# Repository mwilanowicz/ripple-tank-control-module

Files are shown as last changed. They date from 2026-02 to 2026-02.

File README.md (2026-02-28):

# Ripple Tank Control Module
### Engineering Thesis Project | Defended: 9th July, 2024

<p align="center">
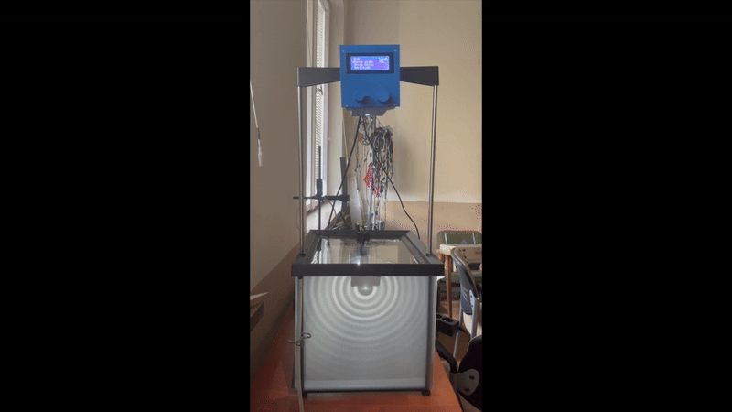
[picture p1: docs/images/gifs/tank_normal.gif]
  
</p>

## Project Overview
This project presents the design and construction of a specialized control module for a **ripple tank:** a laboratory instrument used to demonstrate wave phenomena. The module provides precise regulation of wave parameters and incorporates a stroboscopic effect to "freeze" water ripples for detailed observation.

### Project Scope & Engineering Cycle
The project covers the entire engineering cycle, demonstrating a multidisciplinary approach to hardware design:

* **Electronics:** Advanced circuit design featuring **dual-channel Op-Amp buffers (LM358)**, high-current **MOSFET power stages (IRL540)** for 9V peripherals, and custom DAC implementation via RC filtering.

* **Software:** Real-time, low-jitter signal generation using **AVR Timer1 interrupts (ISR)** for synchronized stroboscopic effects and signal modulation.

* **Mechanics:** Custom-designed housing and mounts developed in **SolidWorks**, optimized for structural stability and laboratory ergonomics.

---

## 1. Project Evolution: From CAD to Reality

A key part of this project was the integration of mechanical design with electronics. The enclosure was designed from scratch in SolidWorks to accommodate the custom internal hardware and user interface.

<div align="center">

| View | 3D CAD Model (SolidWorks) | Final Physical Prototype |
| :---: | :---: | :---: |
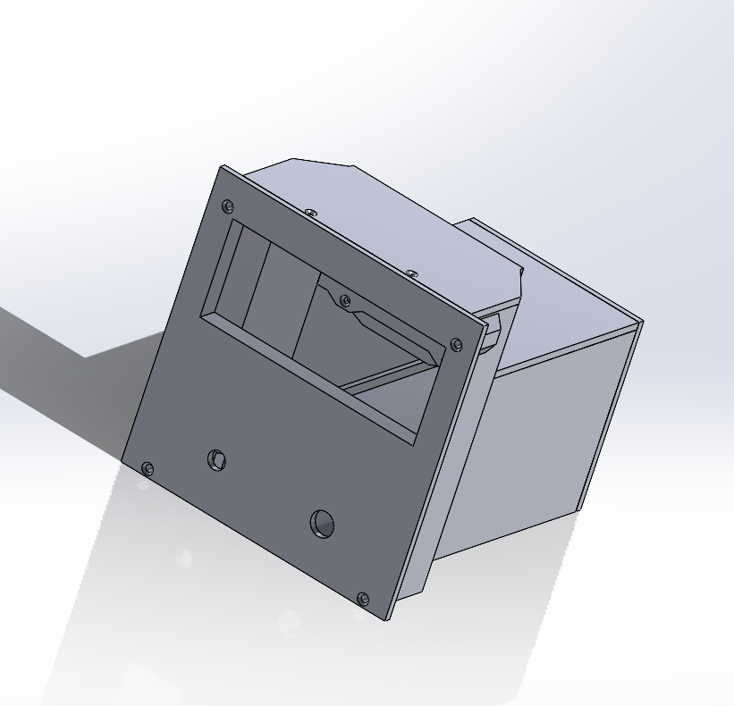
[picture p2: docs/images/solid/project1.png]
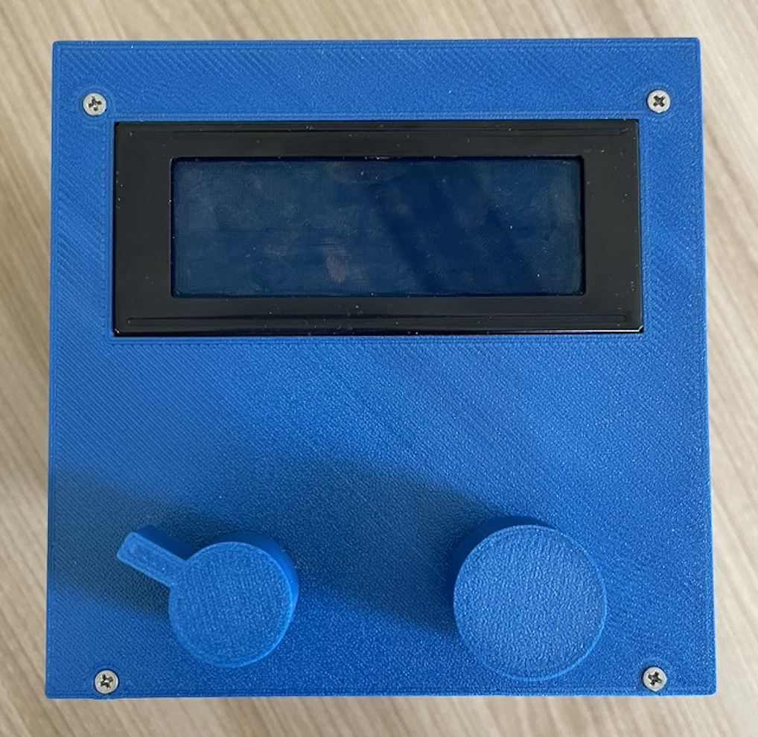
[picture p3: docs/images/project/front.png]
| **Front** |  |  |
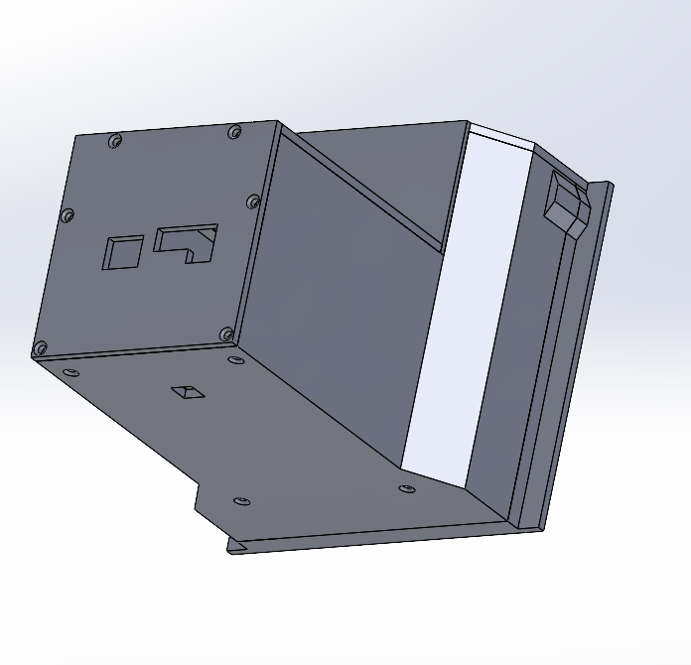
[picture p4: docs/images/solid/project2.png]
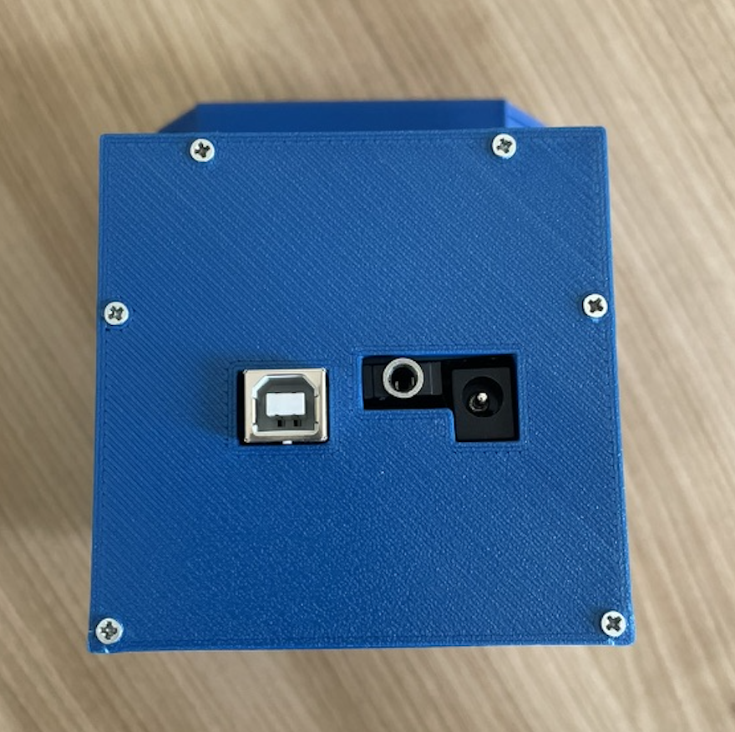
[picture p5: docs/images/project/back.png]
| **Back** |  |  |

</div>

### 1.1 Design Philosophy & Ergonomics
The housing was designed with a clear separation between control and connectivity:

* **Front Panel (User Interface):** Optimized for real-time experimentation. It features:
  * **LCD 20x4 display** for telemetry, 
  
  * **Rotary Encoder** for parameter tuning, 
  
  * **Analog Potentiometer** for high-precision frequency control.

* **Back Panel (Connectivity):** Houses the system's "engine" and external links. Features include:
    * **USB-B Port:** Direct access to the Arduino for firmware updates and serial monitoring.
    
    * **12V DC Power Socket:** Main power input (internally regulated/clamped to 9V by the system for optimal Arduino and peripheral stability).
    
    * **3.5mm Mini-Jack Output:** Dedicated high-current connection for the mechanical actuator (speaker membrane) of the ripple tank system.
    
### 1.3 Internal Layout & Thermal Management
The internal architecture was designed to handle the physical constraints of high-power components within a 3D-printed enclosure:

* **Mounting & Durability:** The top panel features an **integrated mounting point with a heat-set brass insert**. This allows for a robust, threaded connection to the apparatus, preventing the wear and tear typical of threading directly into plastic.

* **Thermal Mitigation Strategy:** High-power resistors and the stroboscopic LED are mounted on a **factory-grade metal plate**. While not a thermal insulator, the plate provides two critical advantages:
    * **Air Gap & Contact Prevention:** It ensures that the heat-generating components have no direct contact with the PLA housing, preventing localized melting.
    * **Passive Heat Spreading:** It acts as a primary heat spreader, distributing thermal energy across its surface area before it reaches the enclosure walls.

* **Internal Clearances:** All internal mounts were modeled in SolidWorks to ensure perfectly aligned access to the USB-B, 3.5mm Jack, and DC Power ports, while maintaining sufficient airflow around the Arduino Proto-Shield.

**Files for 3D printing (STL) can be found here:** [`./hardware/stl`](./hardware/stl)

---

## 2. System Description & Electronics

The hardware architecture is centered around the ATmega328P microcontroller, featuring dedicated analog stages for signal conditioning, power management, and user interface control.

### 2.1 Component Mapping & Signal Path

| Component | Physical Pin | Technical Implementation | Function |
| :--- | :--- | :--- | :--- |
| **Rotary Encoder** | **D5, D6 (Input)** | Digital (Internal Pull-up) | Menu navigation & parameter adjustment |
| **Push Button** | **D7 (Input)** | Digital (Internal Pull-up) | Toggle layers & settings (short) / Save to EEPROM (long) |
| **Potentiometer** | **A1 (Input)** | Analog + Software Hysteresis | Frequency Input: Stable 1–100 Hz adjustment |
| **Speaker** | **D9 (Output)** | Shunt (BC547B) + Buffer + IRL540 | **9V Wave Actuator:** High-speed frequency switching |
| **Strobe LED** | **D4 (Output)** | Buffer (LM358) + MOSFET (IRL540) | **9V Optical Sync:** Precision stroboscopic flash |
| **Arduino Signal** | **D11 (Output)** | PWM + RC Filter ($10\text{k}\Omega/100\mu\text{F}$) | **Amplitude Control:** High-fidelity analog voltage |
| **LCD (I2C 0x3F)** | **A4, A5 (I/O)** | I2C Communication (20x4) | Real-time UI & parameter feedback display |

### 2.2 Circuit Design & Hardware Implementation
The system architecture is based on a structured schematic designed to ensure signal integrity and efficient power distribution. The hardware was implemented as a high-fidelity prototype using a **point-to-point wiring** approach on an Arduino Proto-Shield.

<p align="center">
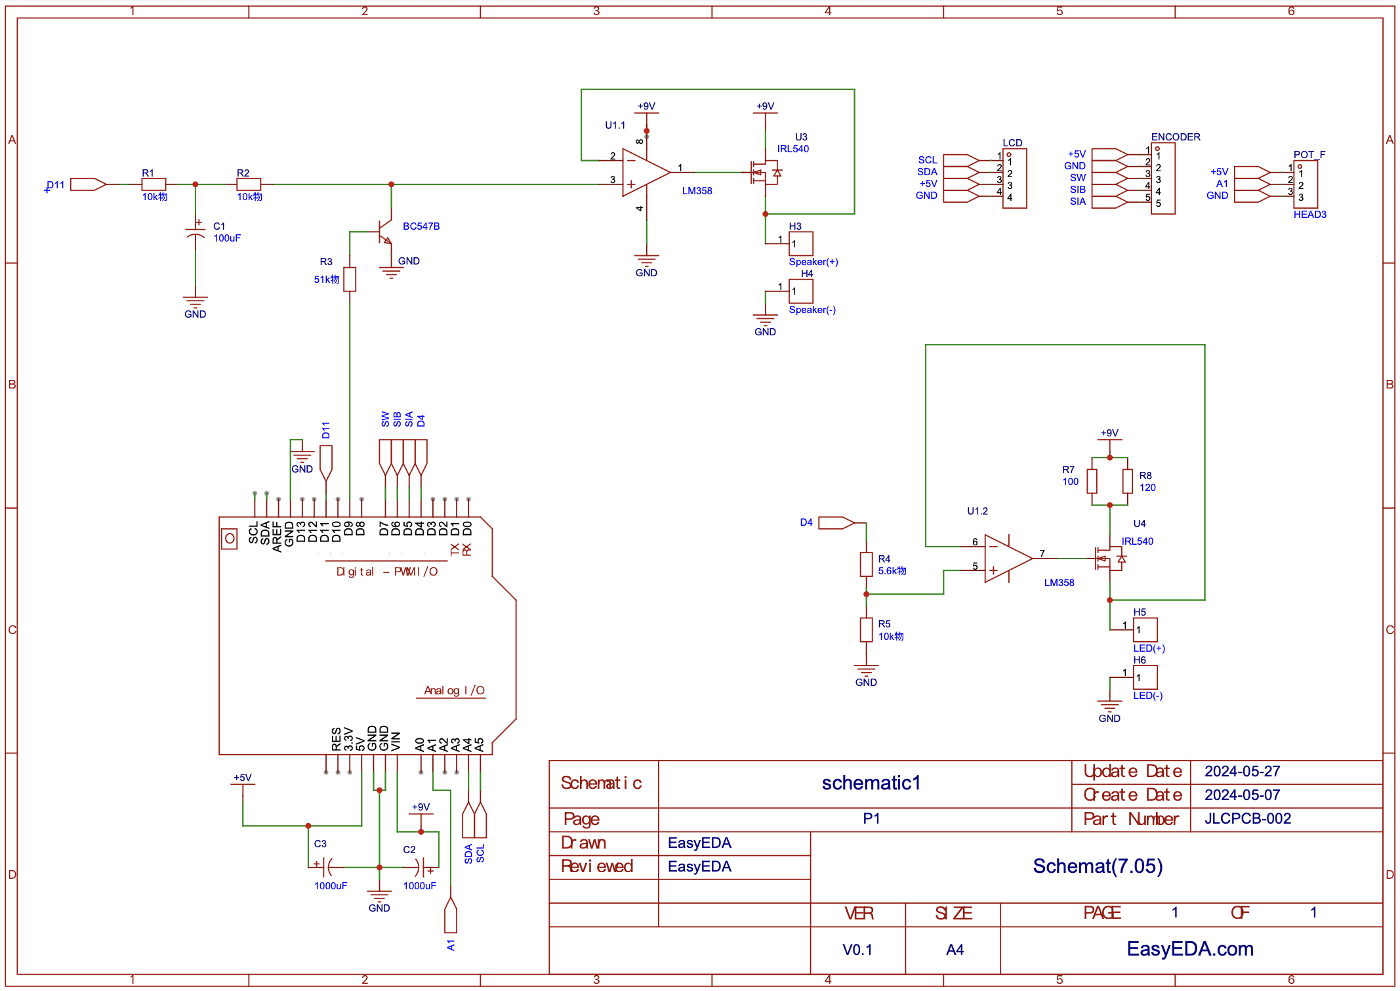
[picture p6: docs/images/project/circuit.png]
Full Electronics Schematic
  
  <br>
  <a href="docs/images/project/circuit_eda.pdf"><strong>📄 Download Full Schematic (PDF)</strong></a>
</p>

To manage high-current loads and overcome the lack of a built-in DAC, the circuit incorporates a dual-channel analog stage with high-current isolation:

* **Control Interface & Signal Modulation:**
    * **Analog Potentiometer (A1):** Dedicated to real-time **Frequency control (D9)**. Provides immediate response by mapping the analog value to `Timer1` registers.
        
      * **Frequency Modulation:** A **BC547B NPN shunt** on pin D9 "chops" the DC reference to ground, providing zero-latency frequency switching without affecting the RC-filter capacitor's charge.
       
    * **Rotary Encoder (D5, D6, D7):** Manages the digital UI menu and fine-tunes the following parameters:
    
      * **Amplitude (D11)**: Generated via a PWM-to-DC **RC filter** ($10\text{k}\Omega / 100\mu\text{F}$). Adjusts the **PWM duty cycle**, which the RC filter converts into an analog voltage reference.
  
      * **Strobe Width (D4)**: Sets the duration of the LED flash within the interrupt cycle to eliminate motion blur. 
  
      * **Pulse Delay (D4)**: Adjusts the phase shift between the mechanical wave and the light pulse, allowing the user to "freeze" the wave at different points in its cycle.

* **Dual Active Buffering (LM358):** 
  * Both the Wave Actuator and Stroboscopic LED channels utilize an **LM358 Op-Amp** configured as a **Voltage Follower**. This provides high input impedance to protect the control signals and low output impedance to drive the power MOSFETs without voltage drops.

* **High-Power Output Stage (9V Rail):** 
  * Two **IRL540 Power MOSFETs** act as the final drivers for the actuator and LED. By drawing current directly from the **9V power rail**, they isolate the 5V logic from high-current spikes and prevent system instability.

* **Stroboscopic LED Precision:** The LED drive includes a voltage divider ($5.6\text{k}\Omega / 10\text{k}\Omega$) and **parallel power resistors** to distribute heat dissipation, ensuring the high-intensity LED operates at a safe 3.2V / 100mA point.

* **Power Integrity:** Massive **1000µF decoupling capacitors** are placed across both the 5V and 9V rails to stabilize the supply during simultaneous operation of the mechanical actuator and LED pulses.
  
---

## 3. Software Architecture & Implementation

The firmware focuses on non-blocking execution and low-level hardware control.

### 3.1 Functional Specification

- **PWM and Pulse Control**
Frequency, duty cycle, and pulse parameters are generated using **Timer1 in CTC mode** for high precision. This allows for manual control over the AVR timers (`TCCR1A`, `TCCR1B`), essential for scientific experiments where timing jitter must be minimized.

- **Software Optimization (Lookup Table)**
To ensure instantaneous response and minimize CPU overhead, frequency calculations are performed using a pre-calculated **Lookup Table**. Each entry maps a target frequency to specific **OCR1A** register values.

  **Timer1 Calculation Example ($f_{clk} = 16 \text{ MHz}$):**

    * **100 Hz:** $\frac{16,000,000}{(624+1) \cdot 1} = 25600 \text{ Hz}$ (Internal Interrupt) $\rightarrow 100 \text{ Hz}$ (Final Output)

    * **1 Hz:** $\frac{16,000,000}{(62499+1) \cdot 1} = 256 \text{ Hz}$ (Internal Interrupt) $\rightarrow 1 \text{ Hz}$ (Final Output)
  
<details>
  <summary><b>Click to expand full Frequency Lookup Table (1 Hz – 100 Hz)</b></summary>

| Step (ISR Freq) | Target Frequency | Period ($T$) | OCR1A Value |
| :--- | :--- | :--- | :--- |
| 256 Hz | **1 Hz** | 1000.0 ms | 62499 |
| 512 Hz | **2 Hz** | 500.0 ms | 31249 |
| 768 Hz | **3 Hz** | 333.3 ms | 20832 |
| 1024 Hz | **4 Hz** | 250.0 ms | 15624 |
| 1280 Hz | **5 Hz** | 200.0 ms | 12499 |
| 1536 Hz | **6 Hz** | 166.7 ms | 10415 |
| 1792 Hz | **7 Hz** | 142.9 ms | 8927 |
| 2048 Hz | **8 Hz** | 125.0 ms | 7811 |
| 2304 Hz | **9 Hz** | 111.1 ms | 6943 |
| 2560 Hz | **10 Hz** | 100.0 ms | 6249 |
| 2816 Hz | **11 Hz** | 90.9 ms | 5680 |
| 3072 Hz | **12 Hz** | 83.3 ms | 5207 |
| 3328 Hz | **13 Hz** | 76.9 ms | 4806 |
| 3584 Hz | **14 Hz** | 71.4 ms | 4463 |
| 3840 Hz | **15 Hz** | 66.7 ms | 4165 |
| 4096 Hz | **16 Hz** | 62.5 ms | 3905 |
| 4352 Hz | **17 Hz** | 58.8 ms | 3675 |
| 4608 Hz | **18 Hz** | 55.6 ms | 3471 |
| 4864 Hz | **19 Hz** | 52.6 ms | 3288 |
| 5120 Hz | **20 Hz** | 50.0 ms | 3124 |
| 5376 Hz | **21 Hz** | 47.6 ms | 2975 |
| 5632 Hz | **22 Hz** | 45.5 ms | 2839 |
| 5888 Hz | **23 Hz** | 43.5 ms | 2716 |
| 6144 Hz | **24 Hz** | 41.7 ms | 2603 |
| 6400 Hz | **25 Hz** | 40.0 ms | 2499 |
| 6656 Hz | **26 Hz** | 38.5 ms | 2402 |
| 6912 Hz | **27 Hz** | 37.0 ms | 2313 |
| 7168 Hz | **28 Hz** | 35.7 ms | 2231 |
| 7424 Hz | **29 Hz** | 34.5 ms | 2154 |
| 7680 Hz | **30 Hz** | 33.3 ms | 2082 |
| 7936 Hz | **31 Hz** | 32.3 ms | 2015 |
| 8192 Hz | **32 Hz** | 31.3 ms | 1952 |
| 8448 Hz | **33 Hz** | 30.3 ms | 1892 |
| 8704 Hz | **34 Hz** | 29.4 ms | 1837 |
| 8960 Hz | **35 Hz** | 28.6 ms | 1784 |
| 9216 Hz | **36 Hz** | 27.8 ms | 1735 |
| 9472 Hz | **37 Hz** | 27.0 ms | 1688 |
| 9728 Hz | **38 Hz** | 26.3 ms | 1643 |
| 9984 Hz | **39 Hz** | 25.6 ms | 1601 |
| 10240 Hz | **40 Hz** | 25.0 ms | 1561 |
| 10496 Hz | **41 Hz** | 24.4 ms | 1523 |
| 10752 Hz | **42 Hz** | 23.8 ms | 1487 |
| 11008 Hz | **43 Hz** | 23.3 ms | 1452 |
| 11264 Hz | **44 Hz** | 22.7 ms | 1419 |
| 11520 Hz | **45 Hz** | 22.2 ms | 1387 |
| 11776 Hz | **46 Hz** | 21.7 ms | 1357 |
| 12032 Hz | **47 Hz** | 21.3 ms | 1328 |
| 12288 Hz | **48 Hz** | 20.8 ms | 1301 |
| 12544 Hz | **49 Hz** | 20.4 ms | 1274 |
| 12800 Hz | **50 Hz** | 20.0 ms | 1249 |
| 13056 Hz | **51 Hz** | 19.6 ms | 1224 |
| 13312 Hz | **52 Hz** | 19.2 ms | 1200 |
| 13568 Hz | **53 Hz** | 18.9 ms | 1178 |
| 13824 Hz | **54 Hz** | 18.5 ms | 1156 |
| 14080 Hz | **55 Hz** | 18.2 ms | 1135 |
| 14336 Hz | **56 Hz** | 17.9 ms | 1115 |
| 14592 Hz | **57 Hz** | 17.5 ms | 1095 |
| 14848 Hz | **58 Hz** | 17.2 ms | 1076 |
| 15104 Hz | **59 Hz** | 16.9 ms | 1058 |
| 15360 Hz | **60 Hz** | 16.7 ms | 1040 |
| 15616 Hz | **61 Hz** | 16.4 ms | 1023 |
| 15872 Hz | **62 Hz** | 16.1 ms | 1007 |
| 16128 Hz | **63 Hz** | 15.9 ms | 991 |
| 16384 Hz | **64 Hz** | 15.6 ms | 975 |
| 16640 Hz | **65 Hz** | 15.4 ms | 960 |
| 16896 Hz | **66 Hz** | 15.2 ms | 945 |
| 17152 Hz | **67 Hz** | 14.9 ms | 931 |
| 17408 Hz | **68 Hz** | 14.7 ms | 918 |
| 17664 Hz | **69 Hz** | 14.5 ms | 904 |
| 17920 Hz | **70 Hz** | 14.3 ms | 891 |
| 18176 Hz | **71 Hz** | 14.1 ms | 879 |
| 18432 Hz | **72 Hz** | 13.9 ms | 867 |
| 18688 Hz | **73 Hz** | 13.7 ms | 855 |
| 18944 Hz | **74 Hz** | 13.5 ms | 843 |
| 19200 Hz | **75 Hz** | 13.3 ms | 832 |
| 19456 Hz | **76 Hz** | 13.2 ms | 821 |
| 19712 Hz | **77 Hz** | 13.0 ms | 810 |
| 19968 Hz | **78 Hz** | 12.8 ms | 800 |
| 20224 Hz | **79 Hz** | 12.7 ms | 790 |
| 20480 Hz | **80 Hz** | 12.5 ms | 780 |
| 20736 Hz | **81 Hz** | 12.3 ms | 770 |
| 20992 Hz | **82 Hz** | 12.2 ms | 761 |
| 21248 Hz | **83 Hz** | 12.0 ms | 752 |
| 21504 Hz | **84 Hz** | 11.9 ms | 743 |
| 21760 Hz | **85 Hz** | 11.8 ms | 734 |
| 22016 Hz | **86 Hz** | 11.6 ms | 725 |
| 22272 Hz | **87 Hz** | 11.5 ms | 717 |
| 22528 Hz | **88 Hz** | 11.4 ms | 709 |
| 22784 Hz | **89 Hz** | 11.2 ms | 701 |
| 23040 Hz | **90 Hz** | 11.1 ms | 693 |
| 23296 Hz | **91 Hz** | 11.0 ms | 685 |
| 23552 Hz | **92 Hz** | 10.9 ms | 678 |
| 23808 Hz | **93 Hz** | 10.8 ms | 671 |
| 24064 Hz | **94 Hz** | 10.6 ms | 663 |
| 24320 Hz | **95 Hz** | 10.5 ms | 656 |
| 24576 Hz | **96 Hz** | 10.4 ms | 650 |
| 24832 Hz | **97 Hz** | 10.3 ms | 643 |
| 25088 Hz | **98 Hz** | 10.2 ms | 636 |
| 25344 Hz | **99 Hz** | 10.1 ms | 630 |
| 25600 Hz | **100 Hz** | 10.0 ms | 624 |

</details>

### 3.2 Real-Time Control Logic
* **Non-blocking Interface:** The menu is handled via state-machine logic, ensuring the display updates without interrupting signal generation.
* **Encoder Handling:** Interrupt-driven logic distinguishes between short presses (navigation) and long presses (saving data).

### 3.3 Signal Stability & Hysteresis
* **Analog Debouncing (Hysteresis):** To prevent LCD flickering and frequency "jumping" due to noise on the analog pot, I implemented software hysteresis (`abs(freqValue - lastFreqValue) > 5`).
* **Stroboscopic Synchronization:** LED flashes are precisely timed with wave fronts to enable "freezing" the motion of water for optical analysis.

### 3.4 Data Persistence (EEPROM)
Key experimental parameters (PWM, Strobe Width, Delay, Amplitude) are stored in the **EEPROM**. The system automatically restores the last used configuration upon startup.

### 3.5 Hardware-Timed Interrupts (ISR)
To ensure maximum signal stability, the wave generation logic is decoupled from the main execution loop:
- **Asynchronous Generation:** I implemented an **Interrupt Service Routine (ISR)** triggered by Timer1 in CTC mode.
- **Jitter Elimination:** This guarantees that time-critical tasks (pulse generation and stroboscopic sync) are not delayed by slower I/O operations like LCD updates.

#### Key Implementation Detail: Timer1 ISR
```cpp
ISR(TIMER1_COMPA_vect) {
    divider++;
    if(divider > 255) { 
        digitalWrite(speakerPin, HIGH);
        divider = 0;
        previousMillis = millis();
    }
    else if(divider == dutyCycle) { 
        digitalWrite(speakerPin, LOW);
    }
}
```

**Full source code is available here:** [`software/control-module/control-module.ino`](./software/control-module/control-module.ino)

---

## 4. Testing & Results (Validation)

### 4.1 Signal Validation (Oscilloscope Tests)
The following measurements verify the accuracy of the generated waveforms:

<div align="center">

| Parameter | Measurement | Parameter | Measurement |
| :--- | :---: | :--- | :---: |
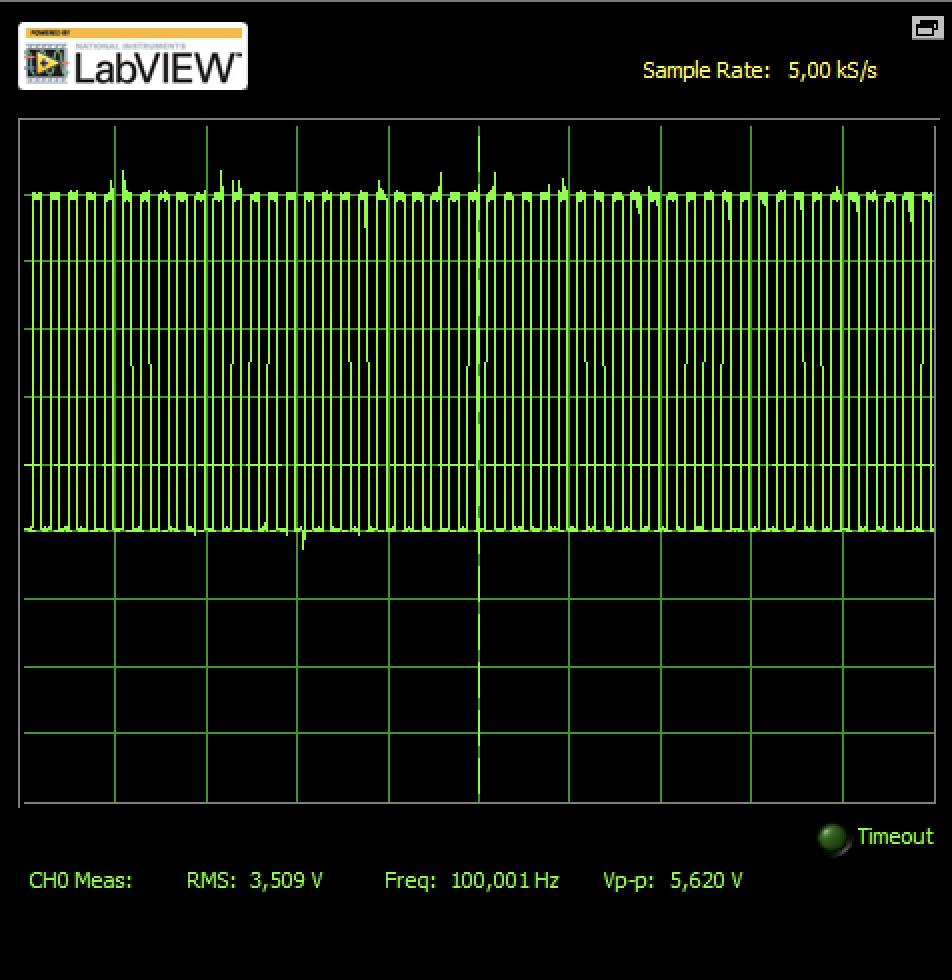
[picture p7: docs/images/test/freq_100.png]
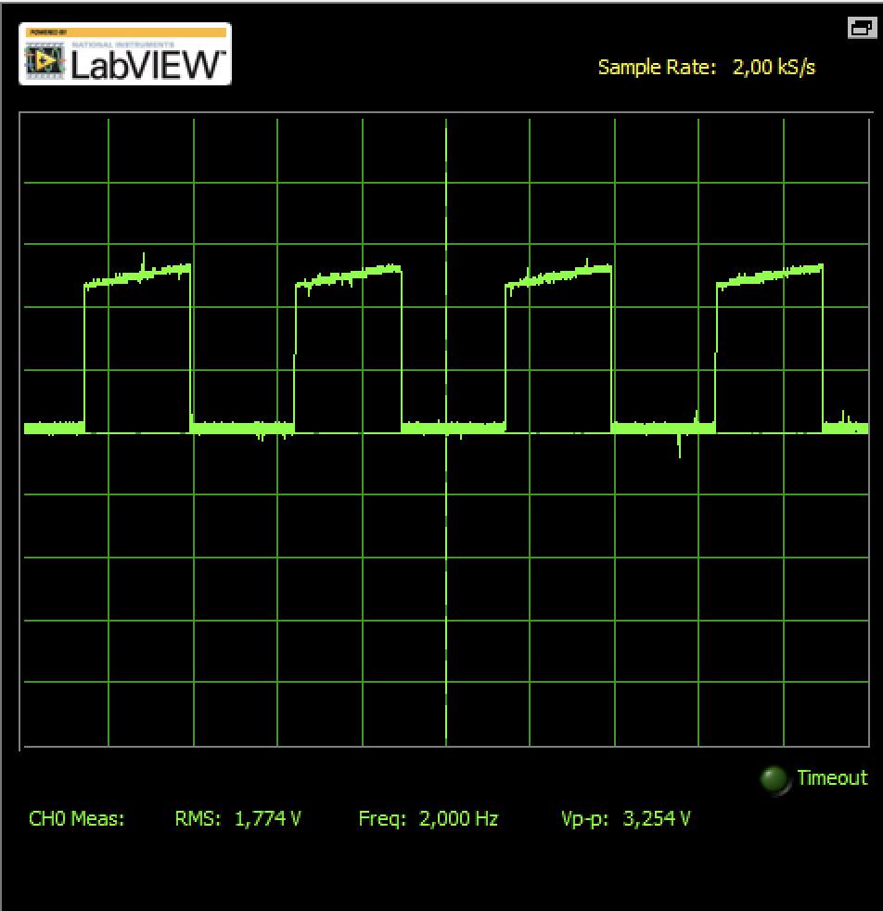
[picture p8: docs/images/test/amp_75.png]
| **Frequency (100 Hz)** |  | **Amplitude (75%)** |  |
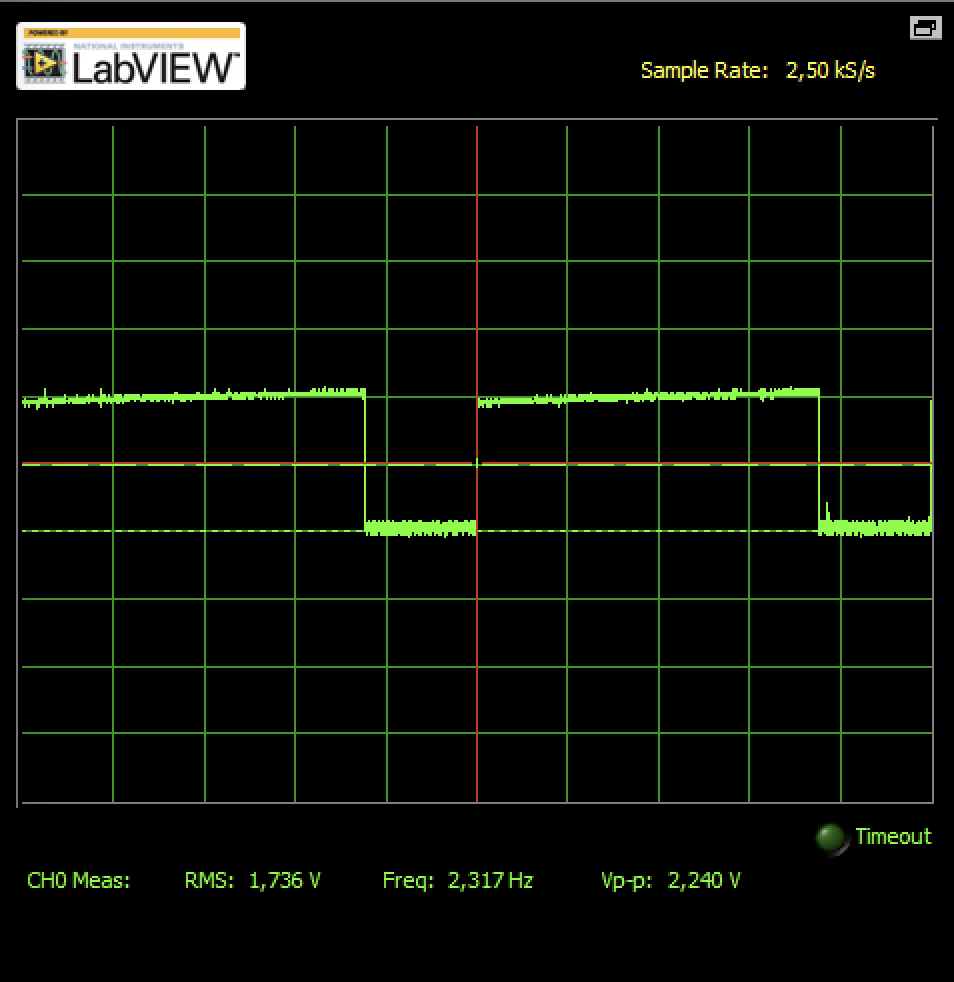
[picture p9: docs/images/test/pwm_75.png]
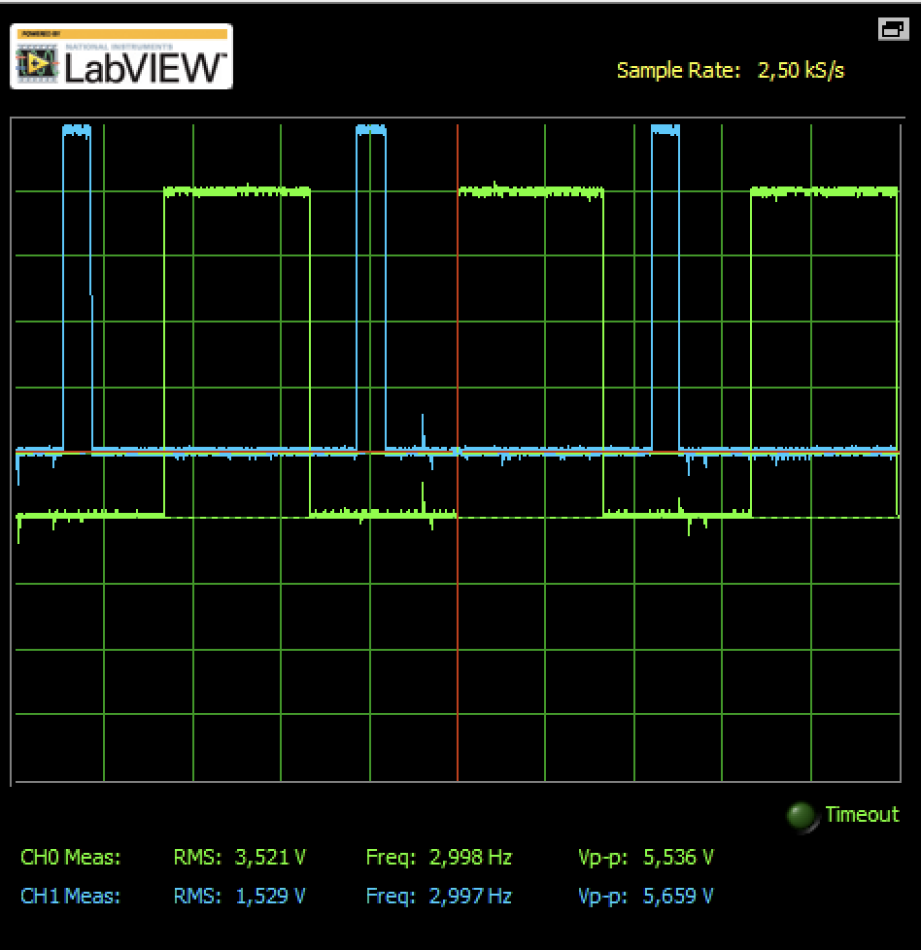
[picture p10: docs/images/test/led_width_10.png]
| **PWM (75%)** |  | **Strobe Width (10%)** |  |
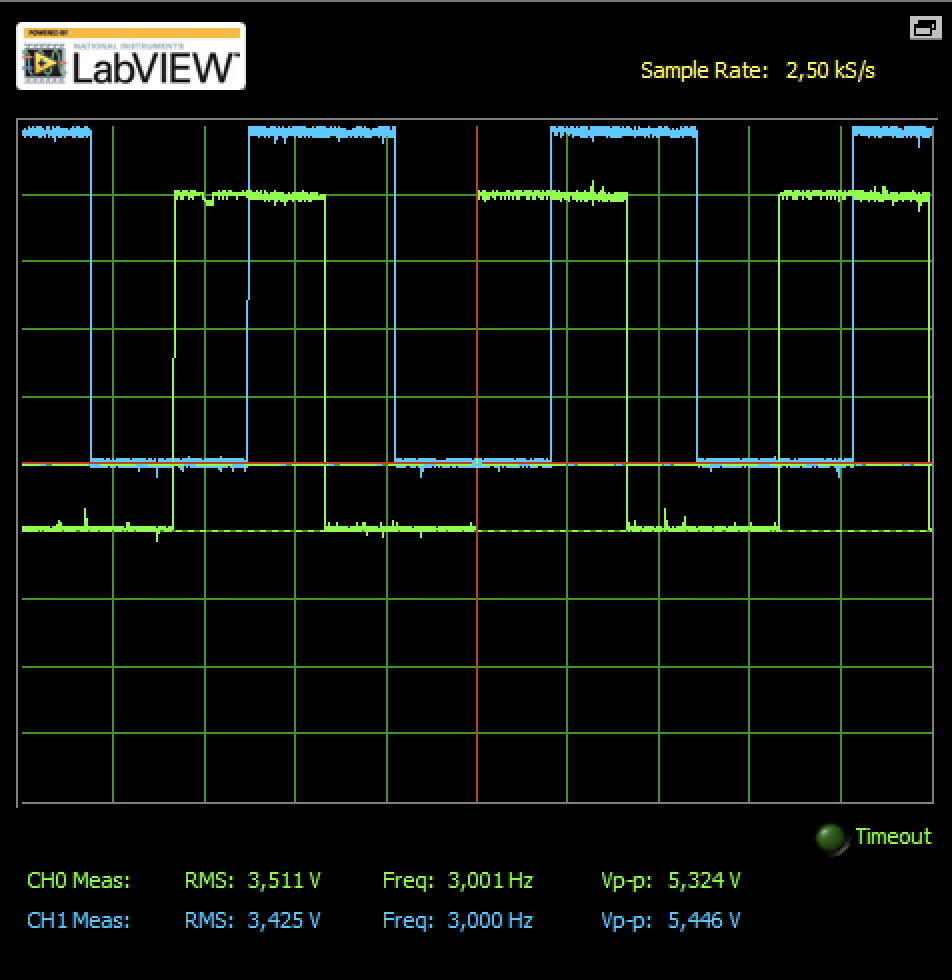
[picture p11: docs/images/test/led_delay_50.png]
| **Pulse Delay (50%)** |  | | |

</div>

### 4.2 Visual Validation: Stroboscopic Effect & Synchronization
The system's ability to "freeze" water ripples for precise observation was verified by correlating the control module's real-time settings with the physical wave output.

<div align="center">

<p align="center">
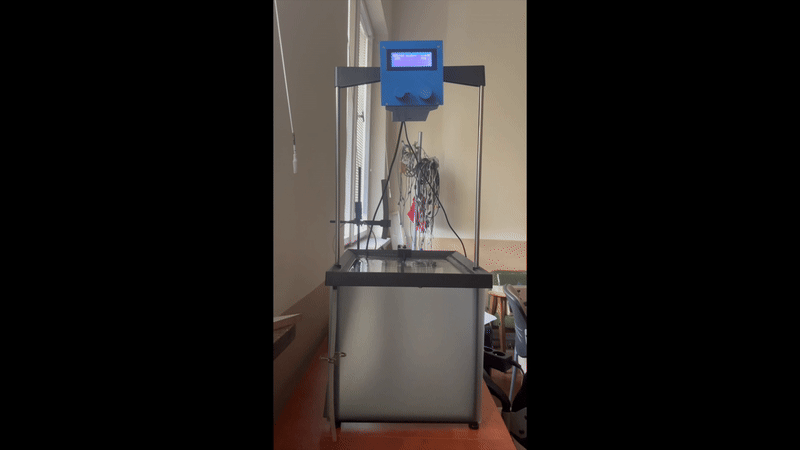
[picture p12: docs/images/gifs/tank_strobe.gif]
  
</p>

| Module Settings (Input) | Wavefront Observation (Output) |
| :---: | :---: |
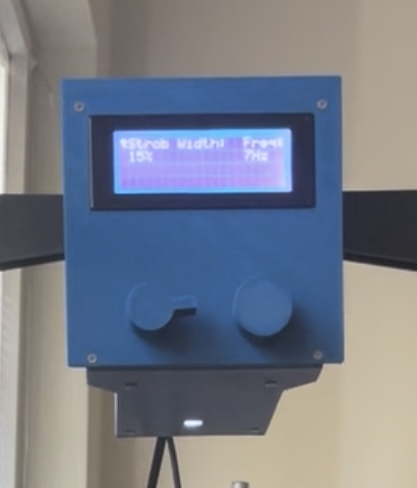
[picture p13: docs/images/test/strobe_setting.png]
LCD Display at 7Hz
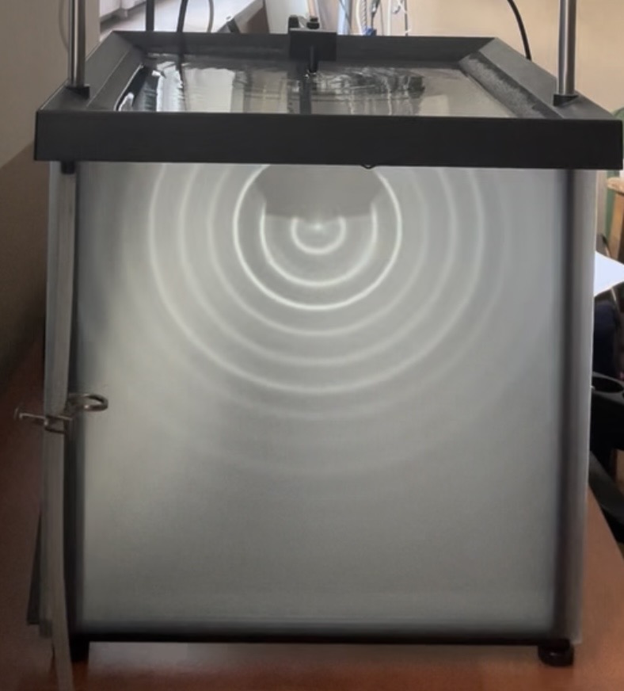
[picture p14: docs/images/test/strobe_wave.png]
Concentric Ripples at 7Hz
|  |  |

</div>

**Technical Observations & Analysis (15% Strobe Width at 7 Hz):**

* **Localized Sharpness:** The stroboscopic "freezing" effect is most prominent near the wave source (actuator), where the wavefronts exhibit high contrast and defined edges.

* **Synchronization Proof:** The clarity of the inner ripples while the actuator is in active motion confirms that the **Timer1 ISR** is correctly triggering the LED pulses in phase with the mechanical vibration.

* **Attenuation & Dispersion:** Further from the center, the wavefronts and reflected light become less distinct. This is a natural result of wave energy attenuation in the medium and the decreasing intensity of reflected light at shallower observation angles.

* **Optical Balance:** The **15% Strobe Width** (visible on the LCD) provides a calibrated balance between sufficient illumination and a pulse duration short enough to minimize motion blur near the source.

* **Phase Adjustment:** By modifying the `Pulse Delay` parameter, the observed wave can be "shifted" in time, enabling the study of phase velocity and interference in a seemingly stationary state.

---

## 5. Tools and Libraries

- **Mechanical Design (CAD):** SolidWorks 
- **Development Environment:** Arduino IDE  
- **Core Libraries:** `Wire.h`, `LiquidCrystal_I2C.h`, `EEPROM.h`
- **Technical References:**
  - [Electronoobs Timer Tutorial](https://electronoobs.com/eng_arduino_tut125.php)
  - [Arduino Button Timing & Debouncing](https://arduinogetstarted.com/tutorials/arduino-button-long-press-short-press)
  - [Arduinoslovakia Timer Cacluator](https://www.arduinoslovakia.eu/application/timer-calculator)

---

**Note:** This repository is a part of an academic thesis project. Full documentation and theoretical background can be found here: [`docs/thesis.pdf`](./docs/thesis.pdf).

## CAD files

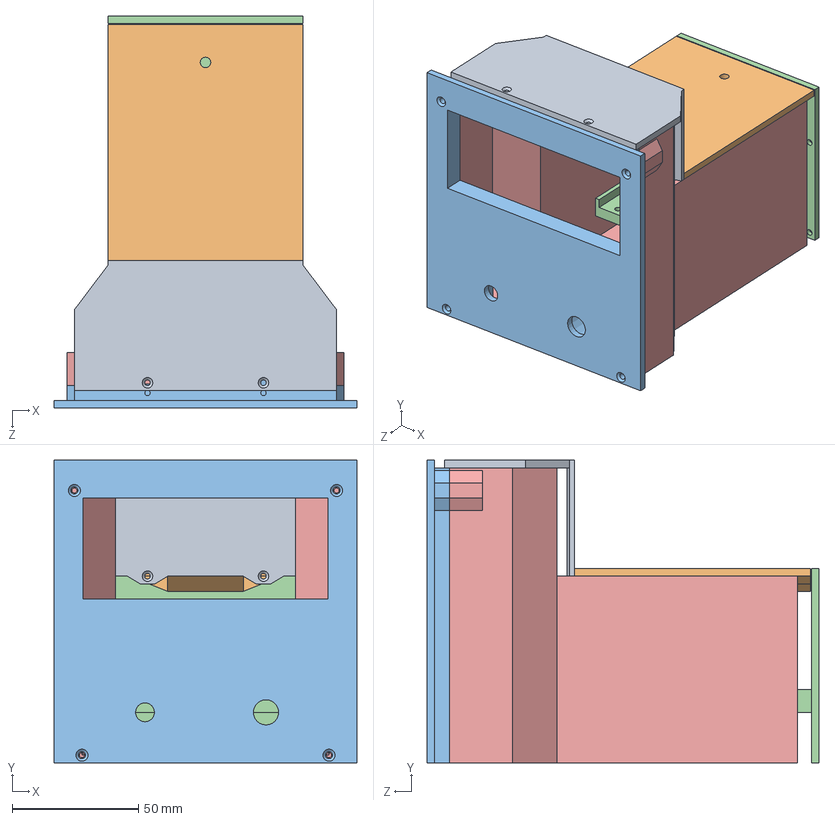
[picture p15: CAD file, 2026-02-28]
hardware/cad/project_assembly.SLDASM
120.0 x 120.0 x 155.5 mm
project_floor
project_back
project_front
project_ceil
project_ceil2

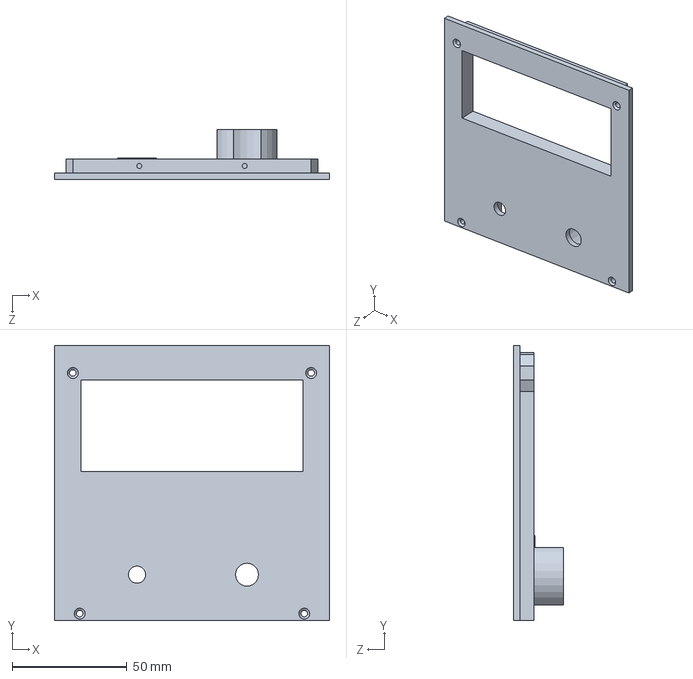
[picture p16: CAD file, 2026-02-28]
hardware/cad/project_front.SLDPRT
120.0 x 120.0 x 22.0 mm

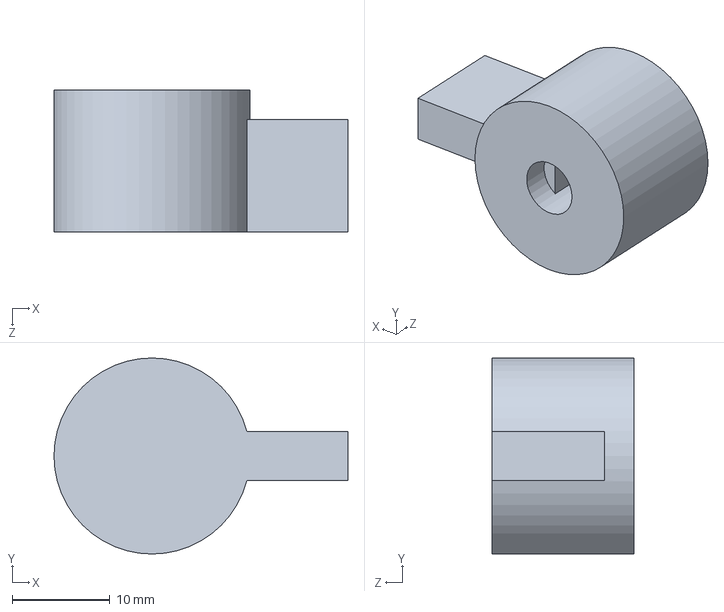
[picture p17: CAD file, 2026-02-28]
hardware/cad/project_knob.SLDPRT
30.0 x 20.0 x 14.5 mm

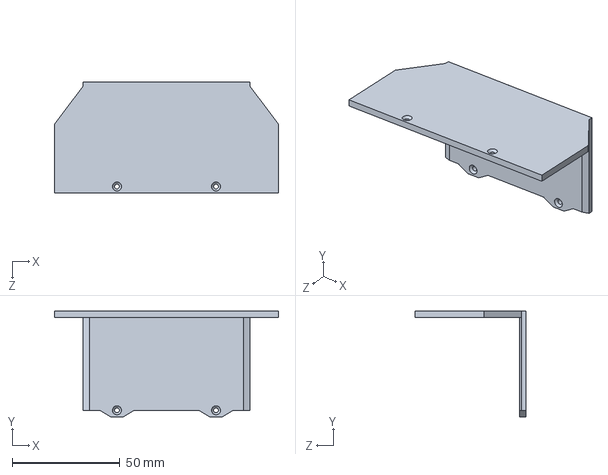
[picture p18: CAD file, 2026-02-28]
hardware/cad/project_ceil2.SLDPRT
104.0 x 49.0 x 51.6 mm

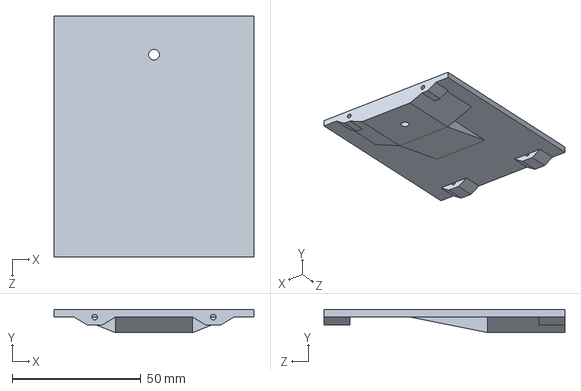
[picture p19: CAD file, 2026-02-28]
hardware/cad/project_ceil.SLDPRT
77.5 x 9.00 x 93.5 mm

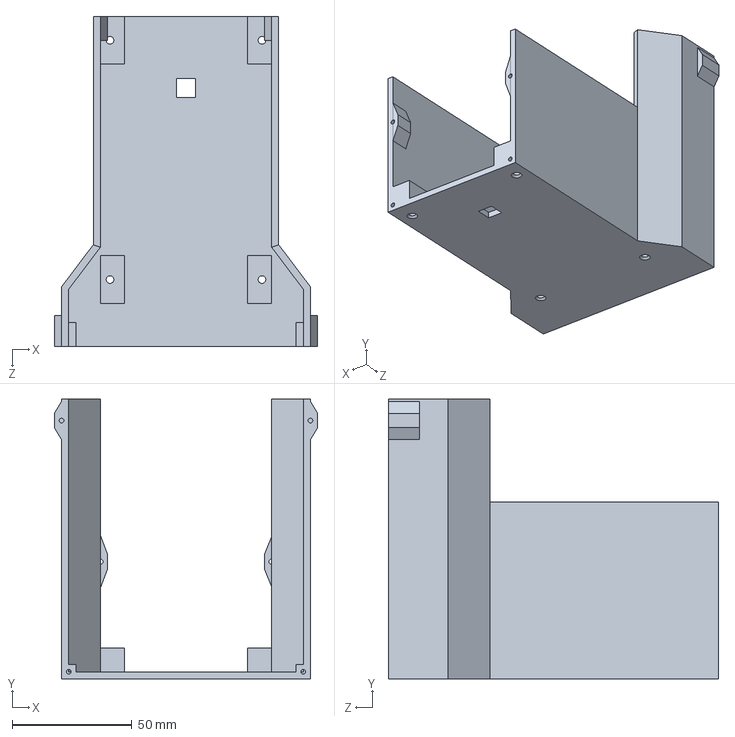
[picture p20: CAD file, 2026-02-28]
hardware/cad/project_floor.SLDPRT
110.0 x 117.0 x 138.0 mm

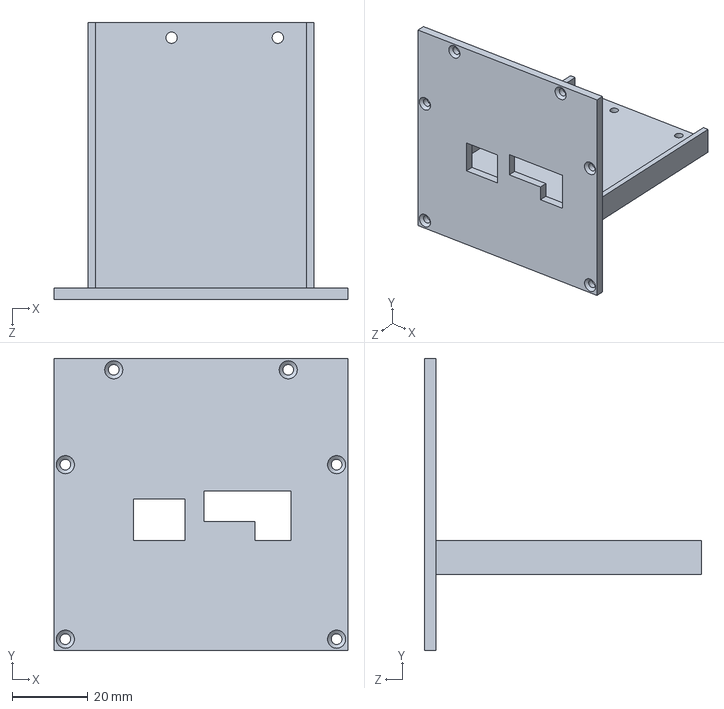
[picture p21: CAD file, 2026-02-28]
hardware/cad/project_back.SLDPRT
77.5 x 77.0 x 73.0 mm

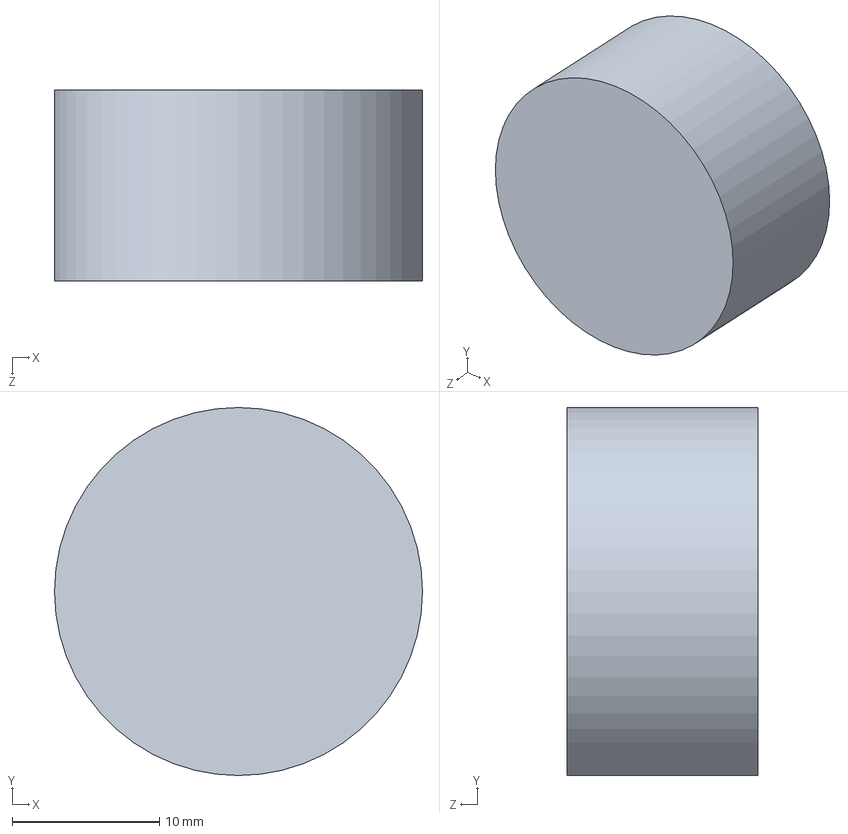
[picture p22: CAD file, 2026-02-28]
hardware/cad/project_knob2.SLDPRT
25.0 x 25.0 x 13.0 mm

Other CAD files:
hardware/cad/project_drawing.SLDDRW
hardware/stl/project_back.STL
hardware/stl/project_ceil.STL
hardware/stl/project_ceil2.STL
hardware/stl/project_floor.STL
hardware/stl/project_front.STL
hardware/stl/project_knob.STL
hardware/stl/project_knob2.STL

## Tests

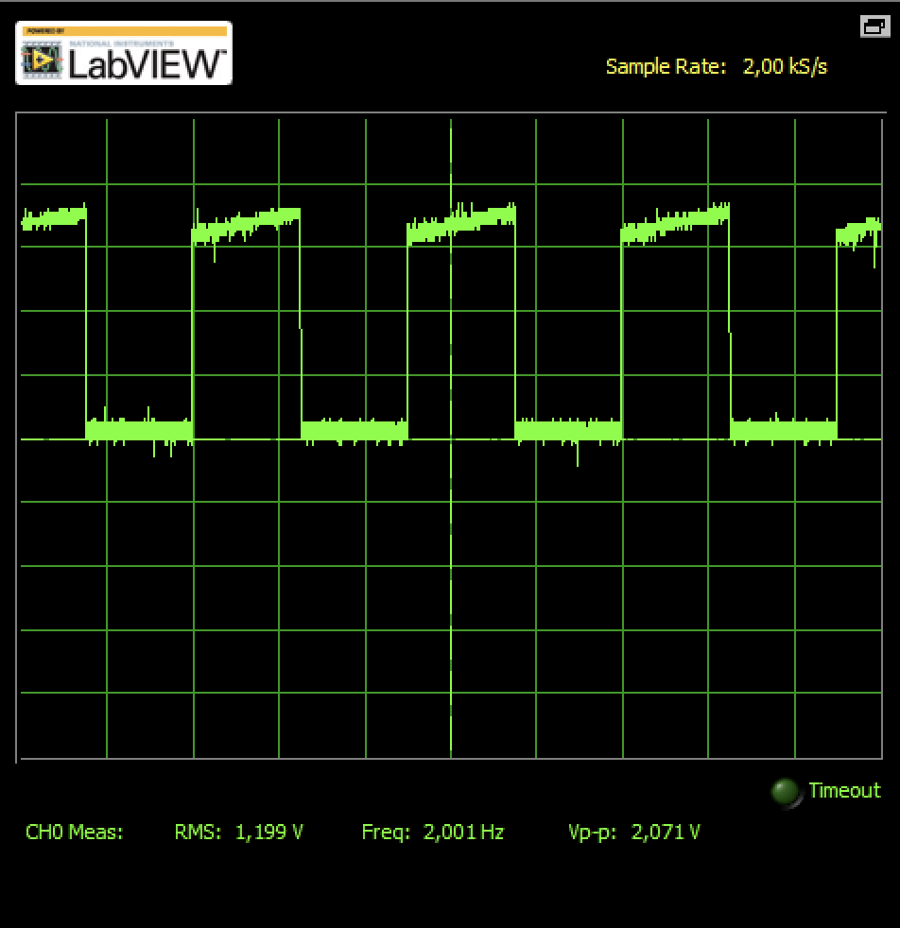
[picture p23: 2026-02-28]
docs/images/test/amp_50.png

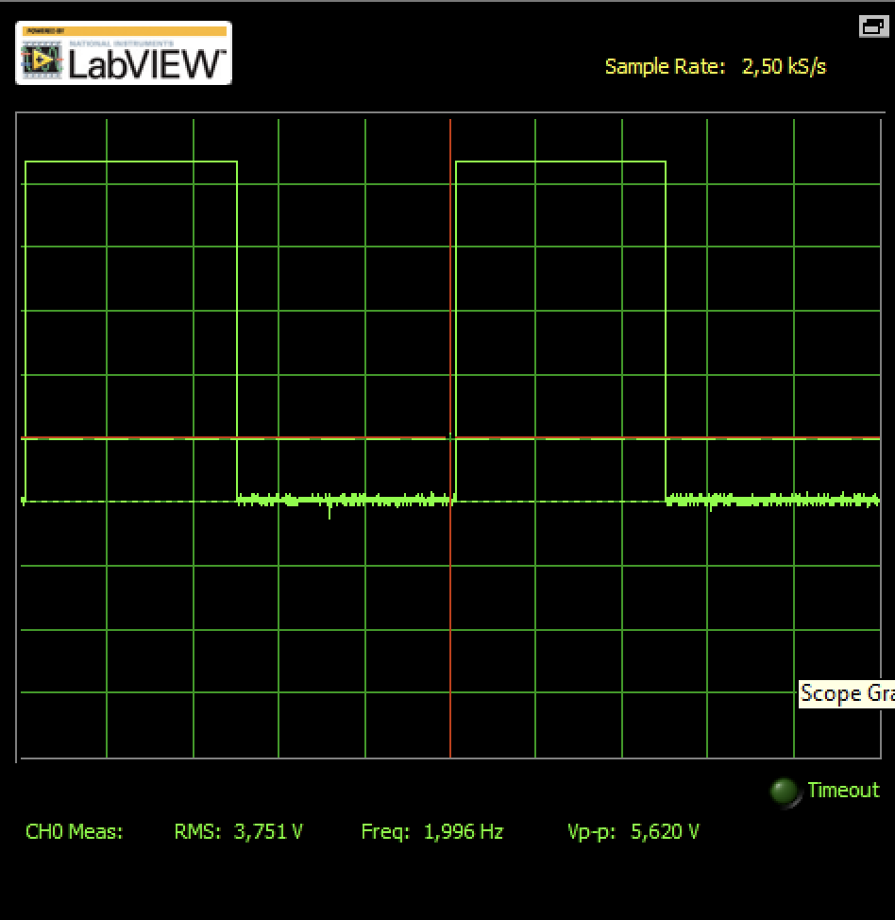
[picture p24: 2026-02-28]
docs/images/test/LED7_TRANZYSOTR.png

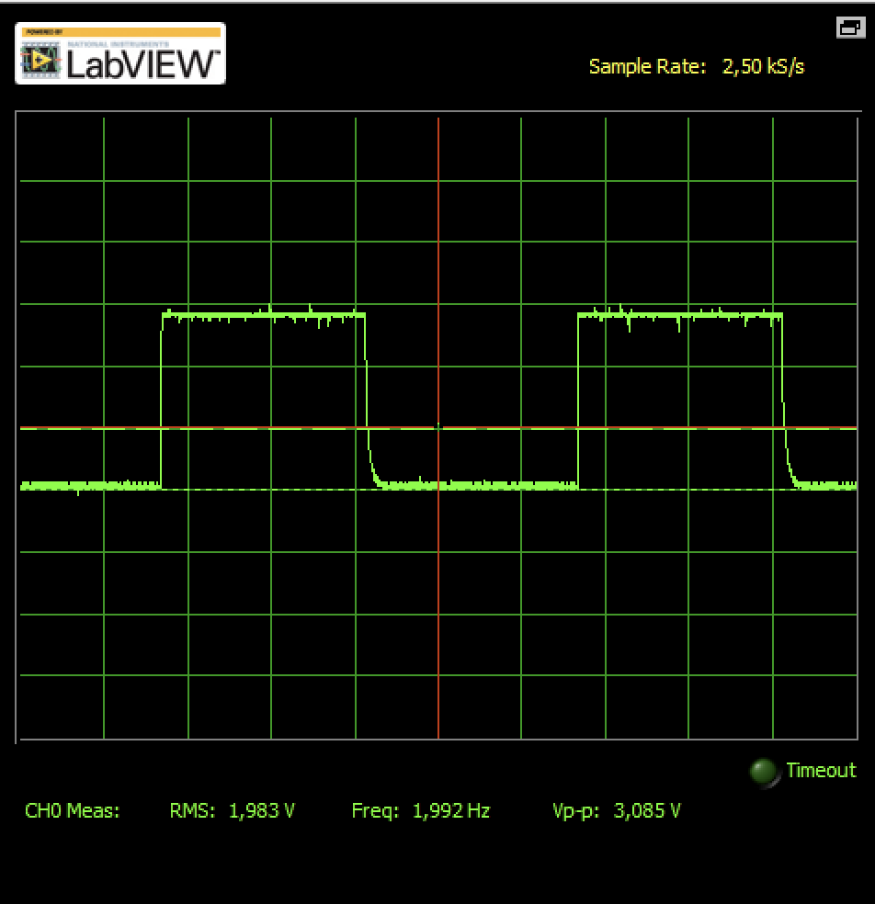
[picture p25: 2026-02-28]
docs/images/test/LED_6_DIODE.png

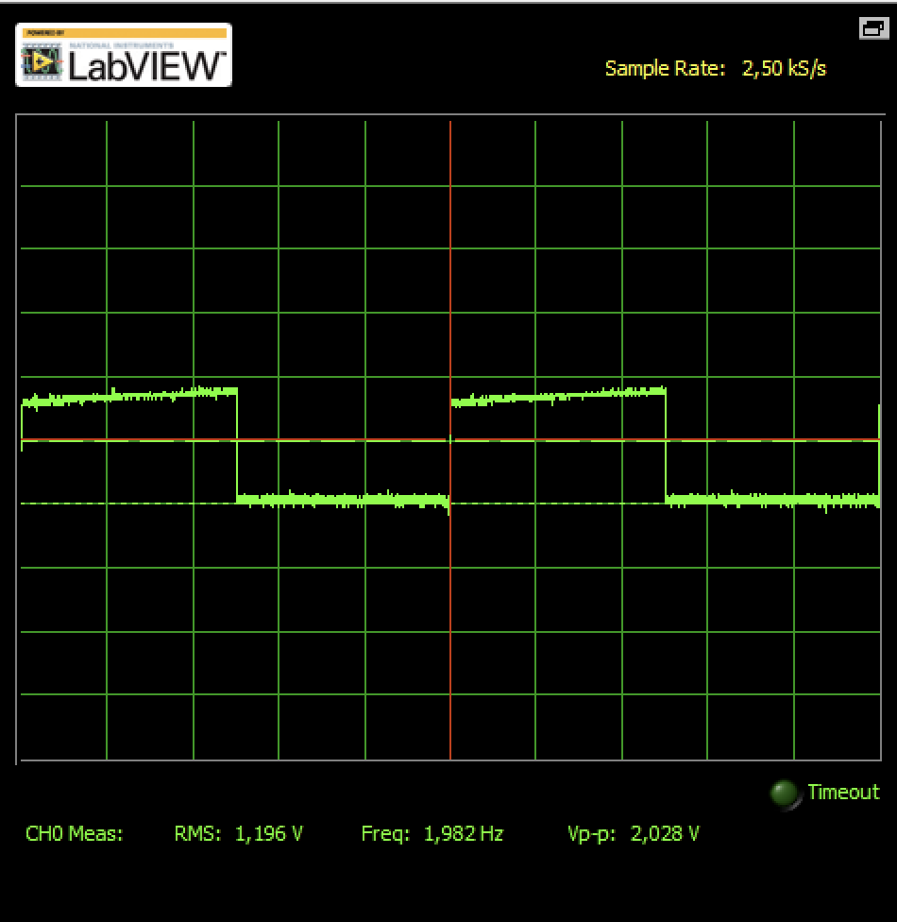
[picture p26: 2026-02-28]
docs/images/test/pwm_50.png

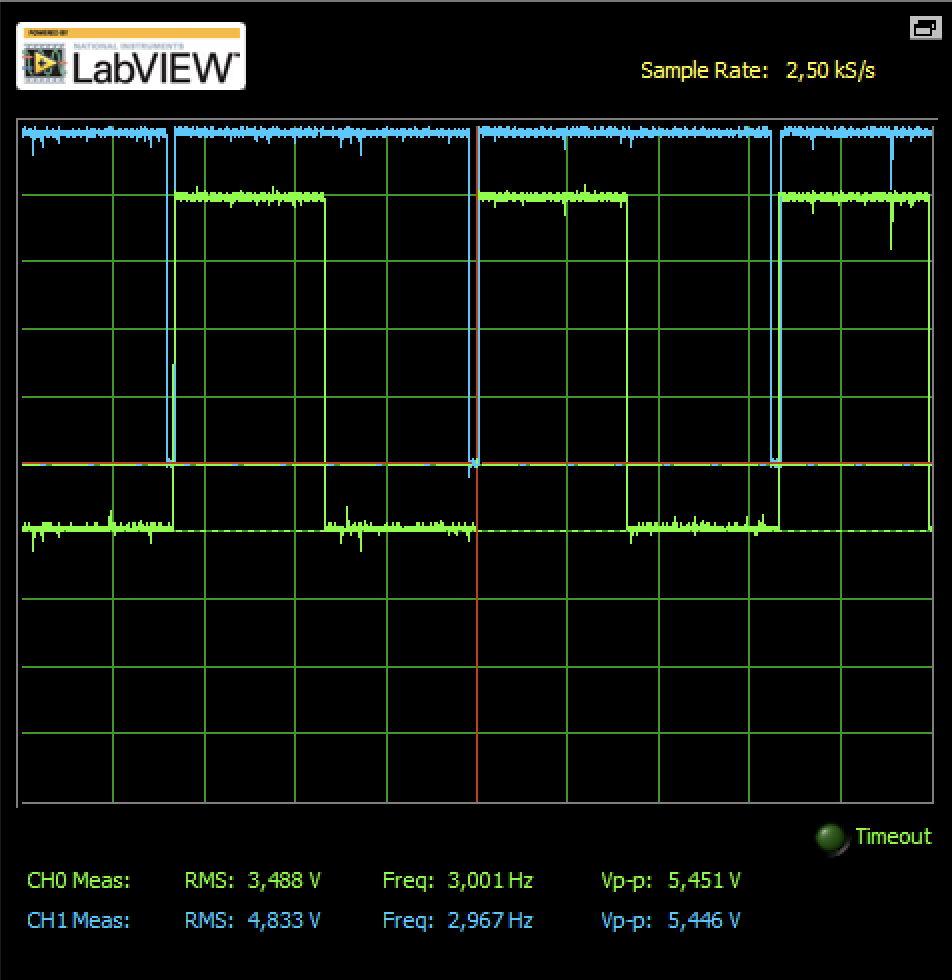
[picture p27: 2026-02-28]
docs/images/test/led_width_100.png

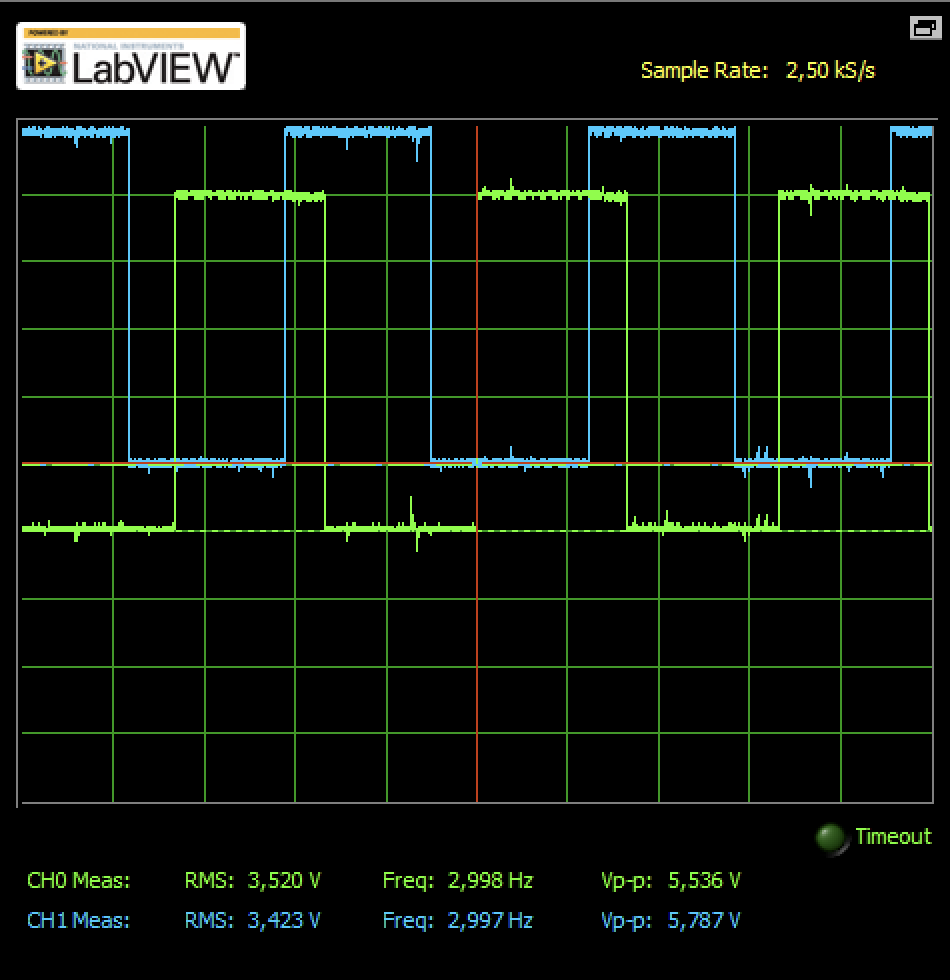
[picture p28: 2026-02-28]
docs/images/test/led_delay_75.png

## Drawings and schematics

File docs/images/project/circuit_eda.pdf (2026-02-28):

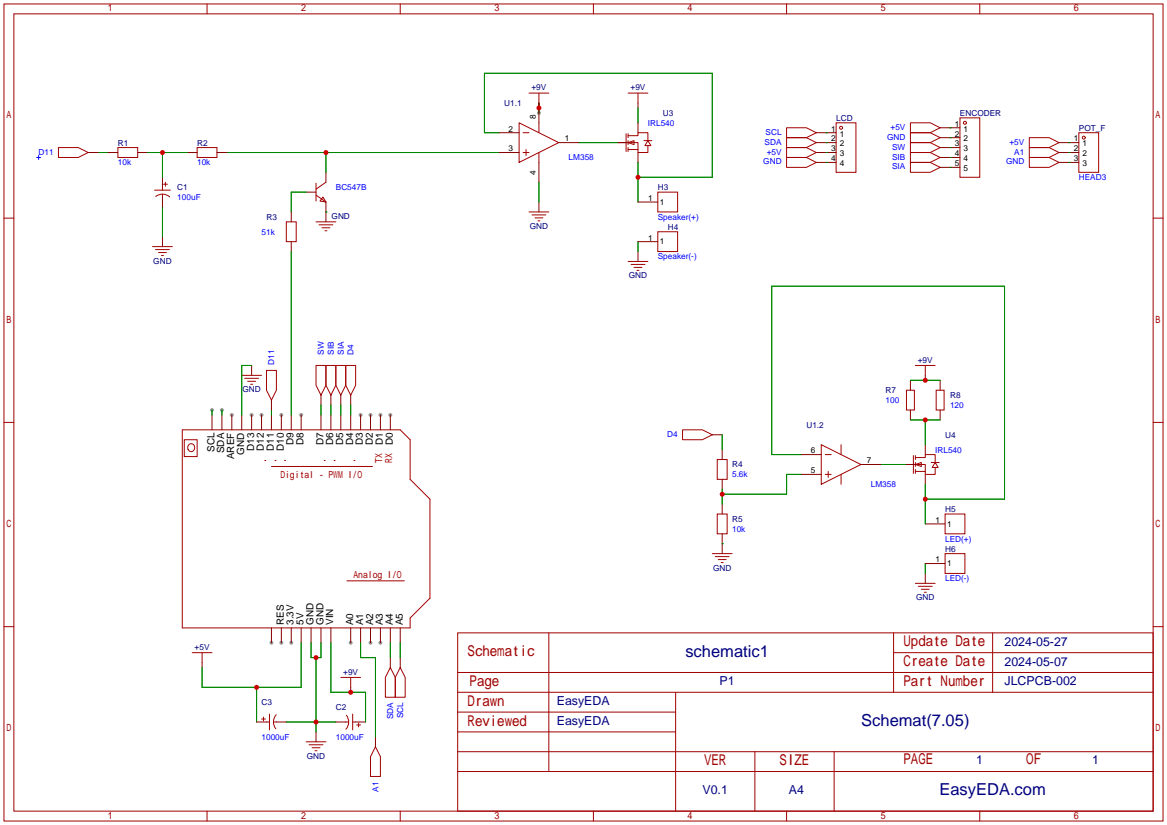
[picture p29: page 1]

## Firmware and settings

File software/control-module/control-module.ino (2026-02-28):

// References:
// https://electronoobs.com/eng_arduino_tut125.php#google_vignette
// https://arduinogetstarted.com/tutorials/arduino-button-long-press-short-press#google_vignette
// https://www.arduinoslovakia.eu/application/timer-calculator

// 25600 Hz (16000000/((624+1)*1)) -> 10ms -> 100 Hz
// 2560 Hz (16000000/((6249+1)*1)) -> 100ms
// 256 Hz (16000000/((62499+1)*1)) -> 1000ms -> 1 Hz

// 256 Hz -> 1000ms -> 1 Hz
// 512 Hz -> 500ms - 2Hz
// 1024 Hz -> 250ms -> 4Hz
// 2048 Hz -> 125ms -> 8Hz

#include <Wire.h>
#include <LiquidCrystal_I2C.h>
#include <EEPROM.h>

LiquidCrystal_I2C lcd(0x3f, 20, 4); // Set the LCD address
int currentLayer = 0; // 0 for main menu, 1 for adjusting settings
int currentSetting = 0; // Tracks which setting is currently being adjusted
int settingsValue[4] = {0, 0, 0, 0}; // Stores values for each setting (pwm, width, delay and amp)

int adjustmentIncrement = 0; // Tracks incremental changes for adjustments

// Custom arrow character (to pointing to a desired setting)
byte arrow[8] = {
  0b00000,  // -----
  0b00100,  // ---*-
  0b00110,  // ---**
  0b11111,  // *****
  0b00110,  // ---**
  0b00100,  // ---*-
  0b00000,  // -----
  0b00000   // -----
};

byte arrowBack[8] = {
  0b00100,  //   *
  0b01110,  //  ***
  0b11111,  // *****
  0b00100,  //   *
  0b00100,  //   *
  0b00111,  //   ***
  0b00000,  //  
  0b00000   //  
};

#define Clock 5   // Clock pin connected to D9
#define Data 6    // Data pin connected to D8
#define Push 7    // Push button pin connected to D7

int counter = 0;                    // Use this variable to store "steps"
int currentStateClock;              // Store the status of the clock pin (HIGH or LOW)
int lastStateClock;                 // Store the PREVIOUS status of the clock pin (HIGH or LOW)
String currentDir ="";              // Use this to print text 
unsigned long lastButtonPress = 0;  // Use this to store if the push button was pressed or not

const int SHORT_PRESS_TIME = 50; // 500 milliseconds for a short press
const int LONG_PRESS_TIME = 500; // 1000 milliseconds for a long press

unsigned long buttonPressTime = 0;  // When the button was pressed
bool isPressing = false;
bool isLongDetected = false;

#define speakerPin 9  // ON/OFF
#define ledPin 4 // Strobe
#define signalPin 11  // Amplitude pwm

#define freqPin A1 // Frequency potentiometer    

volatile int divider = 0;
volatile int dutyCycle = 0;

unsigned long tMax = 0;
unsigned long calcTMax = 0;

int pwmValue = 0; // Zmienna do przechowywania wartości z potencjometru (PWM)
int freqValue = 0; // Zmienna do przechowywania wartości z potencjometru (częstotliwość)
int ampValue = 0;

int lastPwmValue = 0; // Ostatnio zapisana wartość PWM
int lastFreqValue = 0; // Ostatnio zapisana wartość częstotliwości
int lastAmpValue = 0;

unsigned long displayFrequency = 0; // Stores the frequency to be displayed

unsigned long previousMillis = 0;  // will store last time LED was updated

void setupDisplay() {
  lcd.init();
  lcd.backlight();
  lcd.createChar(0, arrow);
  lcd.createChar(1, arrowBack);

  // Draw the menu items
  lcd.setCursor(2, 0); lcd.print("PWM");
  lcd.setCursor(2, 1); lcd.print("Pulse Width");
  lcd.setCursor(2, 2); lcd.print("Pulse Delay");
  lcd.setCursor(2, 3); lcd.print("Amplitude");
}

void updateDisplay() {
    static int lastSetting = -1;
    static int lastLayer = -1;
    static int lastValue = 10; // To detect changes in value for the current setting (change to -1 if not working)
    static unsigned long lastFrequency = 0; // To detect changes in frequency

    // Check if there's a need to update the display
    if (currentLayer != lastLayer || currentSetting != lastSetting || (currentLayer == 1 && settingsValue[currentSetting] != lastValue) || displayFrequency != lastFrequency) {
        lcd.clear();

        if (currentLayer == 0) {
            // Main menu display logic
            lcd.setCursor(0, 0); lcd.print(" PWM");
            lcd.setCursor(0, 1); lcd.print(" Strob Width");
            lcd.setCursor(0, 2); lcd.print(" Strob Delay");
            lcd.setCursor(0, 3); lcd.print(" Amplitude");

            // Move the custom arrow to the current setting
            lcd.setCursor(0, currentSetting); lcd.write(byte(0));  // arrow

            // Display frequency on the right
            lcd.setCursor(15, 0); // Set cursor position for frequency display
            lcd.print("Freq:");
            lcd.setCursor(15, 1); 
            lcd.print(displayFrequency); 
            lcd.print("Hz");
        } else if (currentLayer == 1) {
            // Adjustment layer display logic
            lcd.setCursor(0, 0); lcd.write(byte(1));  // back arrow
            lcd.setCursor(1, 0);
            switch(currentSetting) {
                case 0: lcd.print("PWM:"); break;
                case 1: lcd.print("Strob Width:"); break;
                case 2: lcd.print("Strob Delay:"); break;
                case 3: lcd.print("Amplitude:"); break;
            }
            lcd.setCursor(1, 1);
            lcd.print(settingsValue[currentSetting]); // Display the current value of the setting

            lcd.print("%"); // Assuming settings are represented as percentages
                        // Display frequency on the right
            lcd.setCursor(15, 0); // Set cursor position for frequency display
            lcd.print("Freq: ");
            lcd.setCursor(15, 1); 
            lcd.print(displayFrequency); 
            lcd.print("Hz");
        }

        // Remember the last state to minimize unnecessary updates
        lastLayer = currentLayer;
        lastSetting = currentSetting;
        lastValue = settingsValue[currentSetting];
        lastFrequency = displayFrequency; // Remember the last frequency
    }
}

void setupEncoder() {
  pinMode(Clock, INPUT_PULLUP);
  pinMode(Data, INPUT_PULLUP);
  pinMode(Push, INPUT_PULLUP);
  lastStateClock = digitalRead(Clock);
}

void updateEncoder() {
    currentStateClock = digitalRead(Clock);

    if (currentStateClock != lastStateClock) {
        if (currentStateClock == HIGH) {
            if (currentLayer == 0) {
                // Navigation in the main menu
                if (digitalRead(Data) != currentStateClock) {
                    currentSetting--;
                    if (currentSetting < 0) currentSetting = 3; // Wrap around to the last setting
                } else {
                    currentSetting++;
                    if (currentSetting > 3) currentSetting = 0; // Wrap around to the first setting
                }
            } else if (currentLayer == 1) {
                // Adjusting the current setting's value in the second layer
                if (digitalRead(Data) != currentStateClock) {
                    settingsValue[currentSetting] = max(settingsValue[currentSetting] - 1, 0);
                } else {
                    settingsValue[currentSetting] = min(settingsValue[currentSetting] + 1, 100);
                }
            }
        }
        lastStateClock = currentStateClock;
    }
    // Button press handling
    int btnState = digitalRead(Push);
    static unsigned long buttonDownTime = 0; // Timestamp when the button was pressed
    static bool buttonPressed = false;       // Indicates if the button is currently being pressed

    if (btnState == LOW) {
        if (!buttonPressed) {
            buttonDownTime = millis(); // Record the time when the button was pressed
            buttonPressed = true;
        }
    } else if (btnState == HIGH && buttonPressed) {
        unsigned long pressDuration = millis() - buttonDownTime;
        buttonPressed = false; // Reset the button press state for the next detection

        if (pressDuration >= LONG_PRESS_TIME) {
            // Long press action
            if (currentLayer == 1) {
                // Serial.println("Settings saved (Layer 1, Long Press).");
                saveSetting(currentSetting, settingsValue[currentSetting]);

                // Directly show "Saved" message on the display
                lcd.setCursor(0, 3); // Set the cursor to the bottom line or any desired position
                lcd.print("Saved to memory     "); // Print "Saved" and clear the rest of the line
            }
        } else if (pressDuration >= SHORT_PRESS_TIME && pressDuration < LONG_PRESS_TIME) {
            // Short press action - Toggle between layers
            currentLayer = !currentLayer;
            // Serial.println("Layer toggled by short press.");
        }
    }
}

void saveSetting(int settingIndex, int value) {
  int eepromAddress = settingIndex * 2; // Calculate starting address for the setting
  EEPROM.put(eepromAddress, value);
}

void loadSettings() {
  for (int i = 0; i < 4; i++) {
    int eepromAddress = i * 2; // Calculate starting address for the setting
    int value = 0;
    EEPROM.get(eepromAddress, value);
    settingsValue[i] = value;
  }
}

void setupTimer1() {
  noInterrupts();
  // Clear registers
  TCCR1A = 0;
  TCCR1B = 0;
  TCNT1 = 0;
  
  OCR1A = 65535; 
  // CTC
  TCCR1B |= (1 << WGM12);
  // Prescaler 1
  TCCR1B |= (1 << CS10);
  // Output Compare Match A Interrupt Enable
  TIMSK1 |= (1 << OCIE1A);
  interrupts();
}

void setup() {
  Serial.begin(115200);
  pinMode(speakerPin, OUTPUT);
  pinMode(ledPin, OUTPUT);
  pinMode(signalPin, OUTPUT);
  setupTimer1();
  
  setupEncoder();  // Initialize encoder setup
  setupDisplay();  // Initialize lcd setup
  loadSettings();  // Load saved settings from EPROM
}

void adjustAmplitude() {
    // Map the stored Amplitude percentage (0-100%) to PWM range (0-255)
    int pwmAmplitude = map(settingsValue[3], 0, 100, 0, 255);
    analogWrite(signalPin, pwmAmplitude); // Adjust the amplitude
}

void adjustPWM() {
    // Map the stored PWM percentage (0-100%) to duty cycle range (0-255)
    dutyCycle = map(settingsValue[0], 0, 100, 0, 255);
}

// Define a struct to hold both OCR1A values and the corresponding prescaler setting for easy lookup.
struct FrequencySetting {
    unsigned int ocr1a;
    byte prescalerBits;
};

// Initialize the lookup table with OCR1A values and prescaler settings for frequencies 1Hz to 100Hz.
const FrequencySetting frequencyLookupTable[101] = {
    {65535, 0b000}, // 0 Hz, timer zatrzymany
    {62499, 0b001}, // 256 Hz
    {31249, 0b001}, // 512 Hz
    {20832, 0b001}, // ~768 Hz
    {15624, 0b001}, // 1024 Hz
    {12499, 0b001}, // 1280 Hz
    {10415, 0b001}, // ~1536 Hz
    {8927, 0b001},  // ~1792 Hz
    {7811, 0b001},  // ~2048 Hz
    {6943, 0b001},  // ~2304 Hz
    {6249, 0b001},  // 2560 Hz
    {5680, 0b001},  // ~2816 Hz
    {5207, 0b001},  // ~3072 Hz
    // ...
    {4806, 0b001},  // ~3328 Hz
    {4463, 0b001},  // ~3584 Hz
    {4165, 0b001},  // ~3840 Hz
    {3905, 0b001},  // ~4096 Hz
    {3675, 0b001},  // ~4352 Hz
    {3471, 0b001},  // ~4608 Hz
    {3288, 0b001},  // ~4864 Hz
    {3124, 0b001},  // 5120 Hz
    {2975, 0b001},  // ~5376 Hz
    {2839, 0b001},  // ~5633 Hz
    {2716, 0b001},  // ~5888 Hz
    {2603, 0b001},  // ~6144 Hz
    {2499, 0b001},  // 6400 Hz
    {2402, 0b001},  // ~6658 Hz
    {2313, 0b001},  // ~6914 Hz
    {2231, 0b001},  // ~7168 Hz
    {2154, 0b001},  // ~7424 Hz
    {2082, 0b001},  // ~7681 Hz
    {2015, 0b001},  // ~7936 Hz
    {1952, 0b001},  // ~8192 Hz
    {1892, 0b001},  // ~8452 Hz
    {1837, 0b001},  // ~8705 Hz
    {1784, 0b001},  // ~8963 Hz
    {1735, 0b001},  // ~9216 Hz
    {1688, 0b001},  // ~9473 Hz
    {1643, 0b001},  // ~9732 Hz
    {1601, 0b001},  // ~9987 Hz
    {1561, 0b001},  // ~10243 Hz
    {1523, 0b001}, // ~10498 Hz
    {1487, 0b001}, // ~10752 Hz
    {1452, 0b001}, // ~11011 Hz
    {1419, 0b001}, // ~11267 Hz
    {1387, 0b001}, // ~11527 Hz
    {1357, 0b001}, // ~11782 Hz
    {1328, 0b001}, // ~12039 Hz
    {1301, 0b001}, // ~12288 Hz
    {1274, 0b001}, // ~12549 Hz
    {1249, 0b001}, // 12800 Hz
    {1224, 0b001}, // ~13061 Hz
    {1200, 0b001}, // ~13322 Hz
    {1178, 0b001}, // ~13570 Hz
    {1156, 0b001}, // ~13828 Hz
    {1135, 0b001}, // ~14084 Hz
    {1115, 0b001}, // ~14336 Hz
    {1095, 0b001}, // ~14598 Hz
    {1076, 0b001}, // ~14856 Hz
    {1058, 0b001}, // ~15108 Hz
    {1040, 0b001}, // ~15369 Hz
    {1023, 0b001}, // 15625 Hz
    {1007, 0b001}, // ~15873 Hz
    {991, 0b001},  // ~16129 Hz
    {975, 0b001},  // ~16393 Hz
    {960, 0b001},  // ~16649 Hz
    {945, 0b001},  // ~16913 Hz
    {931, 0b001},  // ~17167 Hz
    {918, 0b001},  // ~17410 Hz
    {904, 0b001},  // ~17679 Hz
    {891, 0b001},  // ~17937 Hz
    {879, 0b001},  // ~18181 Hz
    {867, 0b001},  // ~18433 Hz
    {855, 0b001},  // ~18691 Hz
    {843, 0b001},  // ~18957 Hz
    {832, 0b001},  // ~19207 Hz
    {821, 0b001},  // ~19464 Hz
    {810, 0b001},  // ~19728 Hz
    {800, 0b001},  // ~19975 Hz
    {790, 0b001},  // ~20227 Hz
    {780, 0b001},  // ~20486 Hz
    {770, 0b001},  // ~20752 Hz
    {761, 0b001},  // ~20997 Hz
    {752, 0b001},  // ~21248 Hz
    {743, 0b001},  // ~21505 Hz
    {734, 0b001},  // ~21768 Hz
    {725, 0b001},  // ~22038 Hz
    {717, 0b001},  // ~22284 Hz
    {709, 0b001},  // ~22535 Hz
    {701, 0b001},  // ~22792 Hz
    {693, 0b001},  // ~23054 Hz
    {685, 0b001},  // ~23323 Hz
    {678, 0b001},  // ~23564 Hz
    {671, 0b001},  // ~23809 Hz
    {663, 0b001},  // ~24096 Hz
    {656, 0b001},  // ~24353 Hz
    {650, 0b001},  // ~24577 Hz
    {643, 0b001},  // ~24844 Hz
    {636, 0b001},  // ~25117 Hz
    {630, 0b001},  // ~25356 Hz
    {624, 0b001},  // 25600 Hz
};

void adjustFrequency() {
    // Odczyt wartości z potencjometru podłączonego do freqPin
    freqValue = analogRead(freqPin);
    // Sprawdzenie, czy zmiana wartości przekracza próg 5 (zabezpiecza przed niepożądanymi odczytami)
    if (abs(freqValue - lastFreqValue) > 5) {
    // Mapowanie wartości potencjometru na indeks częstotliwości unsigned int frequencyIndex = map(freqValue, 0, 1023, 0, 100);
    // Pobranie nowych wartości OCR1A i preskalera z tablicy ustawień częstotliwości
    unsigned int newOCR1A = frequencyLookupTable[frequencyIndex].ocr1a;
    byte newPrescalerBits = frequencyLookupTable[frequencyIndex].prescalerBits;
    // Aktualizacja nowych wartości OCR1A i preskalera w rejestrach timera
    OCR1A = newOCR1A;
    TCCR1B = (TCCR1B & 0b11111000) | newPrescalerBits;
    // Obliczanie rzeczywistej częstotliwości na podstawie OCR1A
    unsigned long frequency = 16000000 / (OCR1A + 1);
    // Mapowanie częstotliwości timera na właściwy zakres wyświetlania (1-100 Hz)
    displayFrequency = map(frequency, 256, 25600, 1, 100);
    // Obliczanie okresu sygnału w mikrosekundach
    tMax = (1000000 / frequency);
    // Mapowanie okresu sygnału na właściwy zakres (10-1000 ms)
    calcTMax = map(tMax, 39, 3906, 10, 1000);
    // Zapisywanie bieżącej wartości potencjometru
    lastFreqValue = freqValue;
    } 
}

void loop() {
  adjustAmplitude();
  adjustPWM();
  adjustFrequency();

  unsigned int pulseWidth = map(settingsValue[1], 0, 100, 0, calcTMax);
  unsigned int pulseDelay = map(settingsValue[2], 0, 100, 0, (calcTMax - pulseWidth));
  
  // Warunki dla diody LED:
  unsigned long currentMillis = millis();
  if (currentMillis - previousMillis >= pulseDelay + pulseWidth) {
    digitalWrite(ledPin, LOW);
  } else if (currentMillis - previousMillis >= pulseDelay) {
    digitalWrite(ledPin, HIGH);
  }

  updateEncoder(); // Continuously read and update encoder state
  updateDisplay(); // Continuously read and update lcd state
}

ISR(TIMER1_COMPA_vect) {  // interrupt service routine (ISR)
  //digitalWrite(13, digitalRead(13)^1);
  divider++;
  if(divider > 255) { // wartosc o która spowalniamy
    digitalWrite(speakerPin, HIGH);
    divider = 0;
    previousMillis = millis();
  }
  else if(divider == dutyCycle) { // szerokosc wypelnienia: dla 127 -> 50%
    digitalWrite(speakerPin, LOW);
  }
}
